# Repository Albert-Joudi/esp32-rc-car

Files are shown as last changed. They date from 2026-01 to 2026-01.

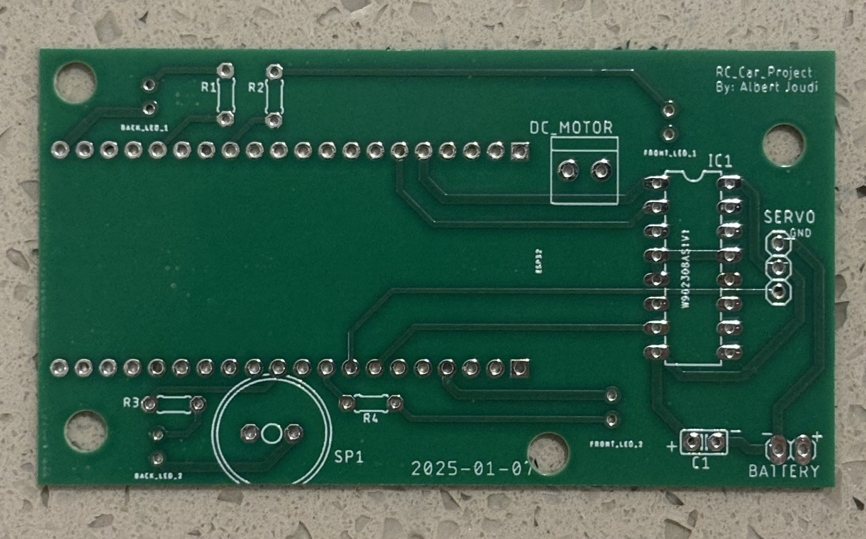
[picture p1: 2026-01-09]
media/esp32_rc_car_pcb_front_unassembled.png

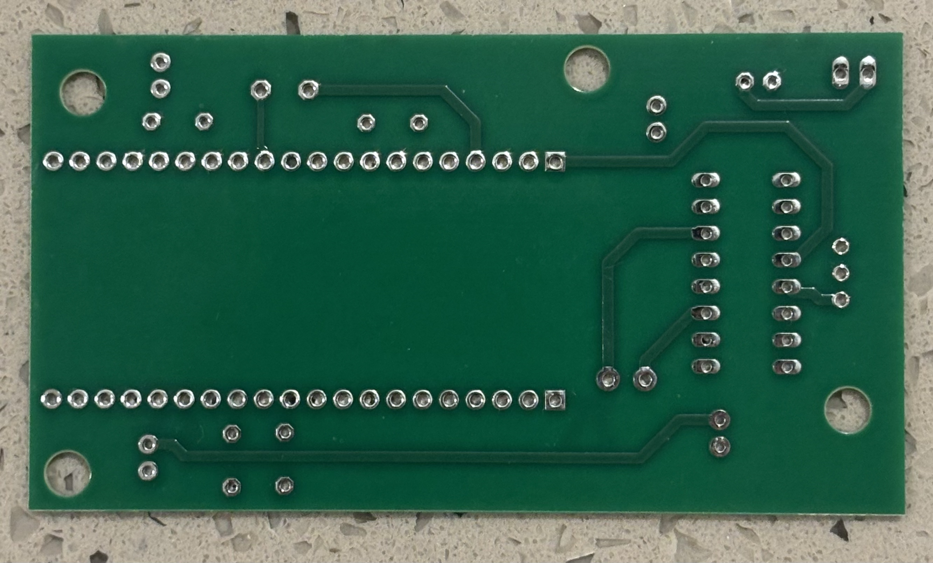
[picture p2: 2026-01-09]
media/esp32_rc_car_pcb_back_unassembled.png

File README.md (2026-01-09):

# esp32-rc-car

## Overview
The **esp32-rc-car** is a custom-built RC car controlled via Bluetooth Low Energy (BLE) using an ESP32 microcontroller. The vehicle is operated from a smartphone through the Dabble app, which provides a virtual game controller interface. The project combines embedded programming, custom PCB design, motor control, and hardware debugging.

---

## Project Media
<p align="center">
  
  
</p>
▶ Watch the ESP32 RC Car features showcase: https://youtube.com/shorts/to-kIwxq354?si=jSNwVrnpMwx3RoQd 

▶ Watch the full demo video of the ESP32 RC Car: https://youtube.com/shorts/JepBfLC0xiw?si=qRIe9IqqiM_V_Yjg

---

## Features
- BLE-based wireless control using the ESP32
- Smartphone control via the Dabble app game controller
- Start/Stop system similar to a real car ignition
- DC motor for forward and reverse motion
- Servo motor for left and right steering
- Front headlights and rear taillights
- Direction-based lighting:
  - Front LEDs activate when moving forward
  - Rear LEDs activate when reversing
- Turn signals and hazard lights with dedicated controls
- Horn functionality using a speaker
- Visual feedback (LED blinking) when starting/stopping the car

---

## Control System
- The ESP32 uses its built-in **Bluetooth Low Energy (BLE)** to communicate with a smartphone.
- The **Dabble mobile app** provides a game controller interface.
- Button presses in the app are mapped in the Arduino IDE to ESP32 GPIO pins.
- GPIO pins control:
  - DC motor
  - Servo motor
  - LEDs
  - Speaker (horn)

---

## Hardware Components
- ESP32 development board
- DC motor (rear-wheel drive)
- Servo motor (front-wheel steering)
- DRV8833 motor driver
- Speaker (horn)
- 4 LEDs:
  - 2 front headlights
  - 2 rear taillights
- Custom-designed PCB
- Power switch
- 3.7V 1100mAh Li-Po battery
- 6V 2400mAh Ni-MH battery pack

---

## Power Architecture
- **Dual power supply design**:
  - **Li-Po battery** powers the ESP32
    - Includes a physical switch to turn the system on/off
  - **Ni-MH battery pack** powers:
    - DC motor
    - Servo motor
    - LEDs
    - Speaker
- Power distribution for peripherals is handled directly on the custom PCB.

---

## PCB Design
- Custom PCB designed using **Autodesk Eagle**
- Fully **through-hole components**
- ESP32 is mounted using **headers** (not soldered directly)
- Designed for easy debugging, modification, and component replacement
- Initial motor driver (L293D) was replaced with a **DRV8833** after testing revealed insufficient motor drive strength

---

## Software & Tools
- Arduino IDE (ESP32 programming)
- Dabble mobile app (BLE controller interface)
- Autodesk Eagle (PCB design)
- Tinkercad (circuit simulation and early testing)
- Multimeter (circuit testing and debugging)

---

## Development & Debugging
- The circuit was first simulated and tested in **Tinkercad** to verify connections, motor control, and LED functionality before creating the custom PCB.  
- Multiple iterations were required to validate motor control and power delivery.  
- Problems encountered and solved:
  - Motor driver (L293D) was too weak → replaced with DRV8833
  - Front wheels initially had too much friction → wrapped tires in tape to reduce friction and allow smooth steering
  - Servo motor was not strong enough initially → adjustments made to wheel friction for smooth turning  
- Circuit simulation, real-world testing, and incremental debugging ensured reliable operation.

---

## Skills Demonstrated
- ESP32 programming and BLE integration
- Custom PCB design and layout
- Through-hole soldering and hardware assembly
- Motor driver integration and control
- Dual power supply management
- Circuit testing and debugging
- Embedded system troubleshooting
- Hardware problem solving and iterative design improvements

## Future Improvements
- Integrate motor driver directly onto PCB
- Add battery voltage monitoring
- better cable management and enclosed design

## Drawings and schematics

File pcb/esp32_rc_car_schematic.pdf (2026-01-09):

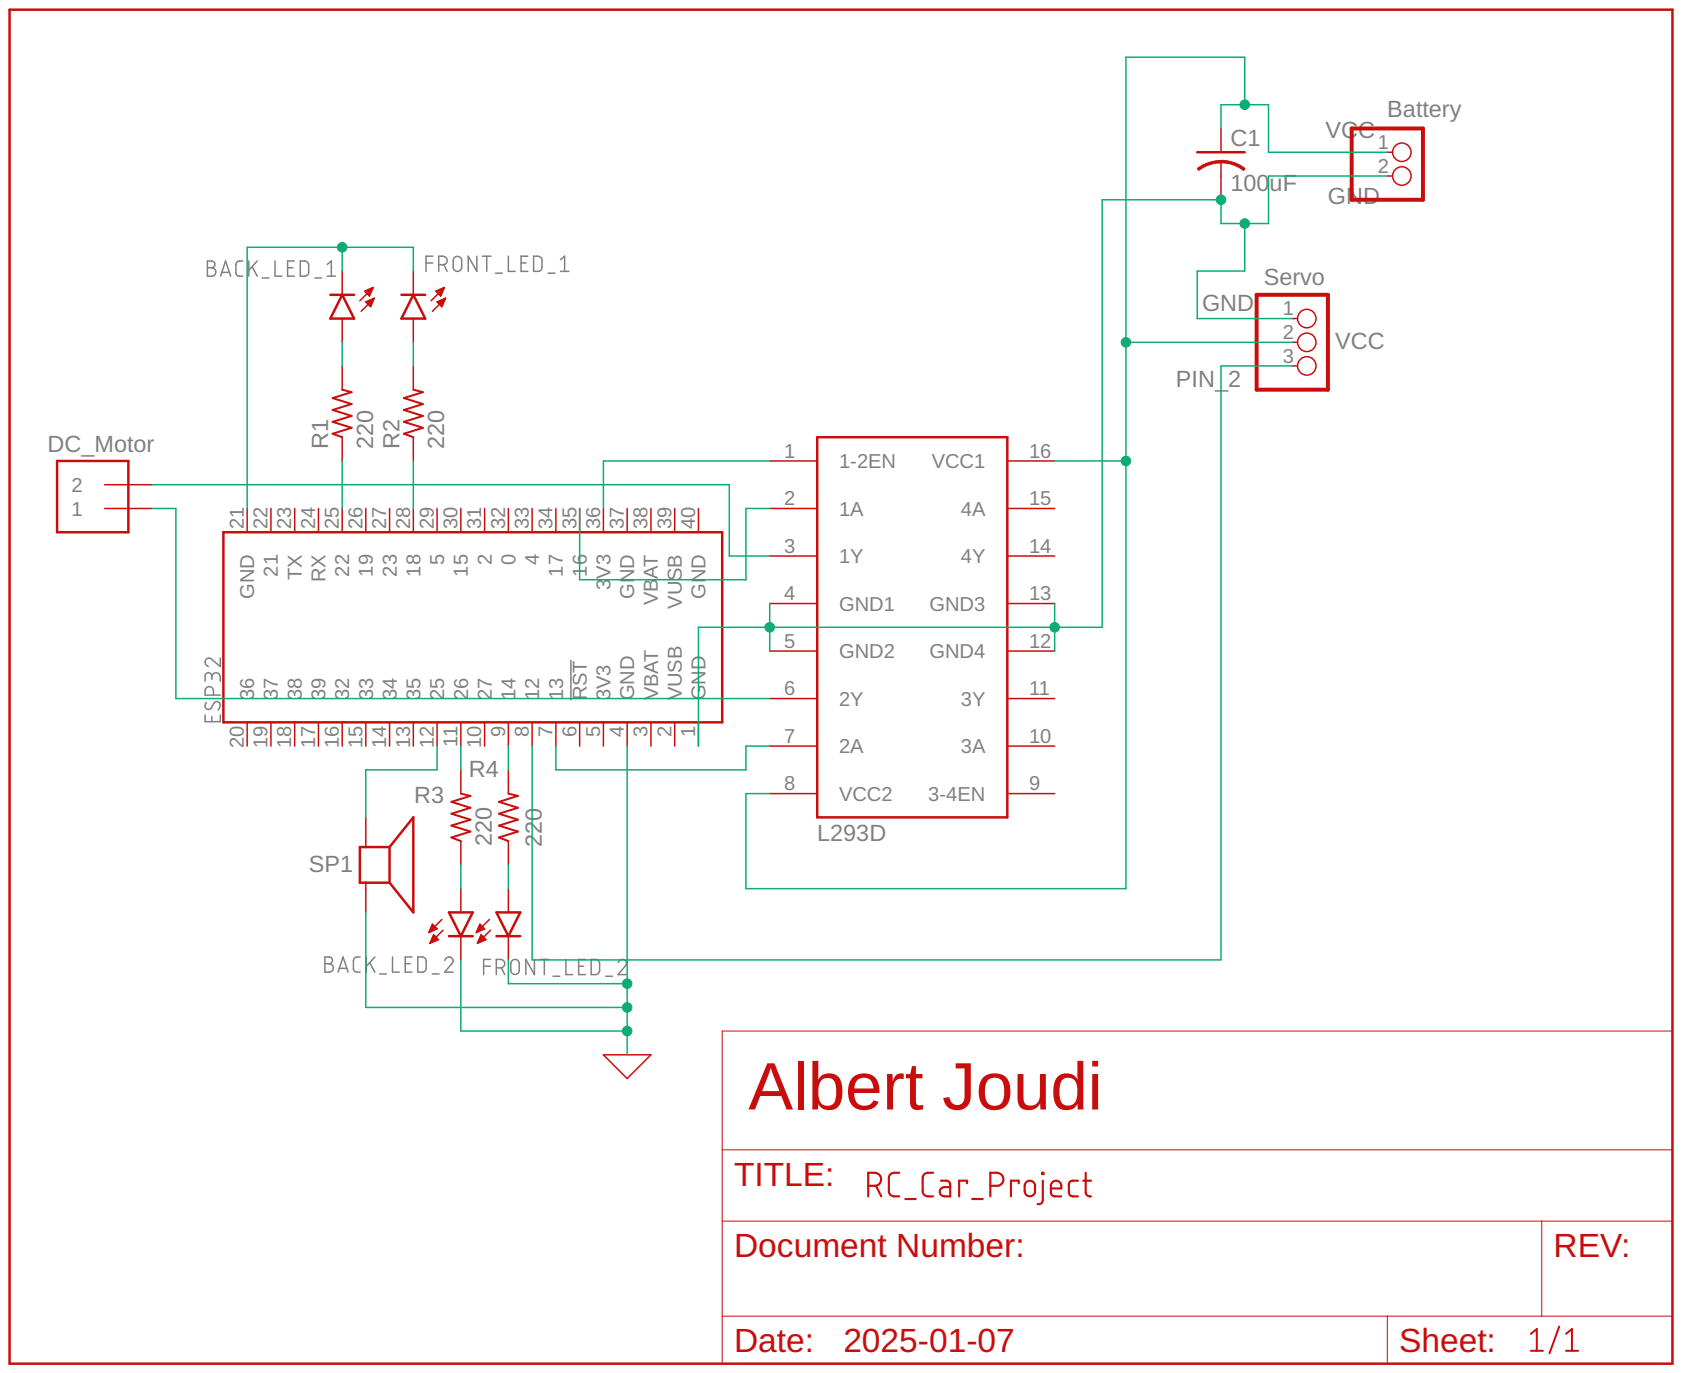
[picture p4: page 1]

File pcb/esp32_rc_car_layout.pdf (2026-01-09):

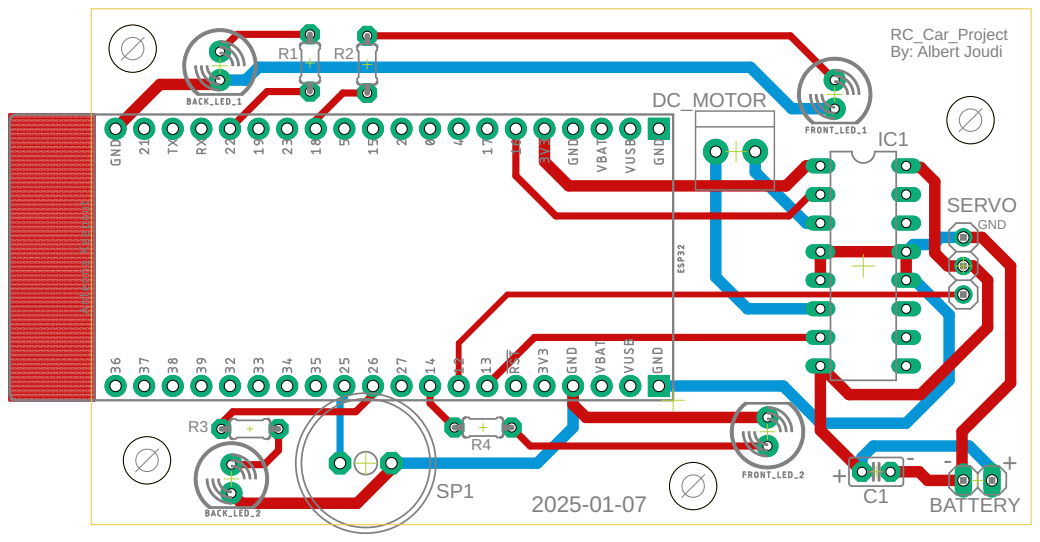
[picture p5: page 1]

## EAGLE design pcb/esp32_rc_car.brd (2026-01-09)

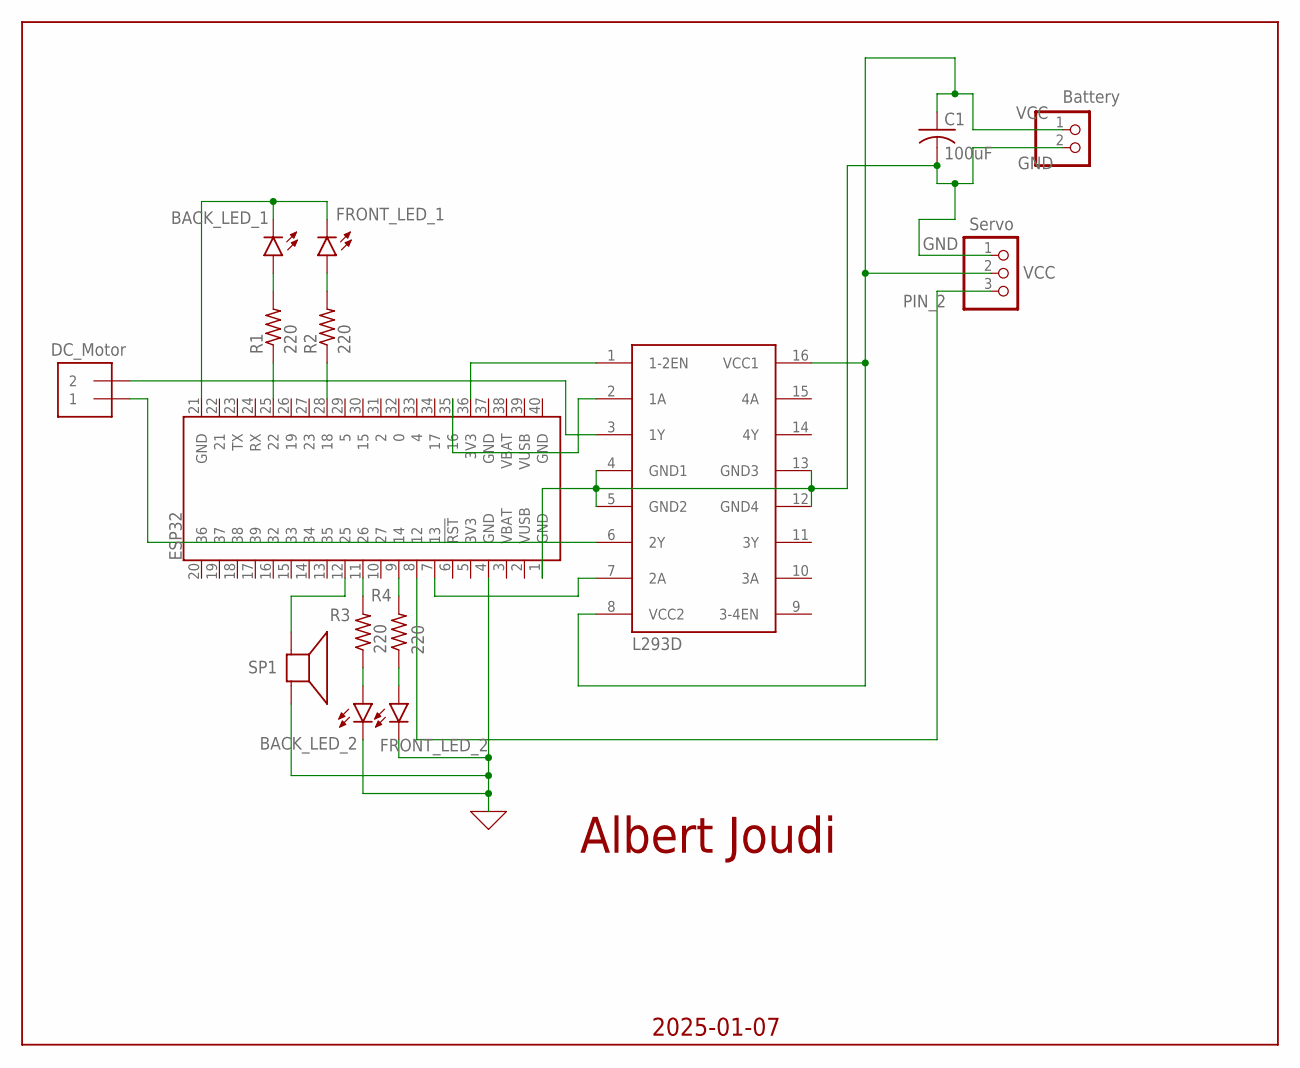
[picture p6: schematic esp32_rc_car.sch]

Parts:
BACK_LED_1, BACK_LED_2: LED-5MM-KIT-NO-SILK; LED_5MM-KIT-NO-SILK
BATTERY: PINHD-1X2; 1X02
C1: 100uF; C025-025X050
DC_MOTOR: 1X2-3.5MM
ESP32: ESP32_THING_W_ANT_KEEPOUT; ESP32_THING
FRONT_LED_1, FRONT_LED_2: LED-5MM-KIT-NO-SILK; LED_5MM-KIT-NO-SILK
IC1: L293D; DIL16
R1, R2, R3, R4: 220; 0204/5
SERVO: PINHD-1X3; 1X03
SP1: SPEAKER/AL11P; AL11P

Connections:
0: BACK_LED_2.K (C), ESP32.4 (GND), FRONT_LED_2.K (C), SP1.-
GND: BATTERY.2, C1.2, ESP32.1 (GND), IC1.4 (GND1), IC1.5 (GND2), IC1.12 (GND4), IC1.13 (GND3), SERVO.1
unnamed: ESP32.12 (25), SP1.+
unnamed: ESP32.35 (16), IC1.2 (1A)
unnamed: DC_MOTOR.2, IC1.3 (1Y)
unnamed: DC_MOTOR.1, IC1.6 (2Y)
unnamed: ESP32.7 (13), IC1.7 (2A)
unnamed: BACK_LED_2.A, R3.1
unnamed: ESP32.28 (18), R2.1
unnamed: ESP32.11 (26), R3.2
unnamed: ESP32.25 (22), R1.1
unnamed: ESP32.9 (14), R4.2
unnamed: FRONT_LED_2.A, R4.1
unnamed: ESP32.36 (3V3), IC1.1 (1-2EN)
unnamed: FRONT_LED_1.A, R2.2
unnamed: BACK_LED_1.A, R1.2
unnamed: BACK_LED_1.K (C), ESP32.21 (GND), FRONT_LED_1.K (C)
PIN_2: ESP32.8 (12), SERVO.3
VCC: BATTERY.1, C1.1, IC1.8 (VCC2), IC1.16 (VCC1), SERVO.2

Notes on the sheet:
Albert Joudi
DC_Motor
Battery
Servo
2025-01-07

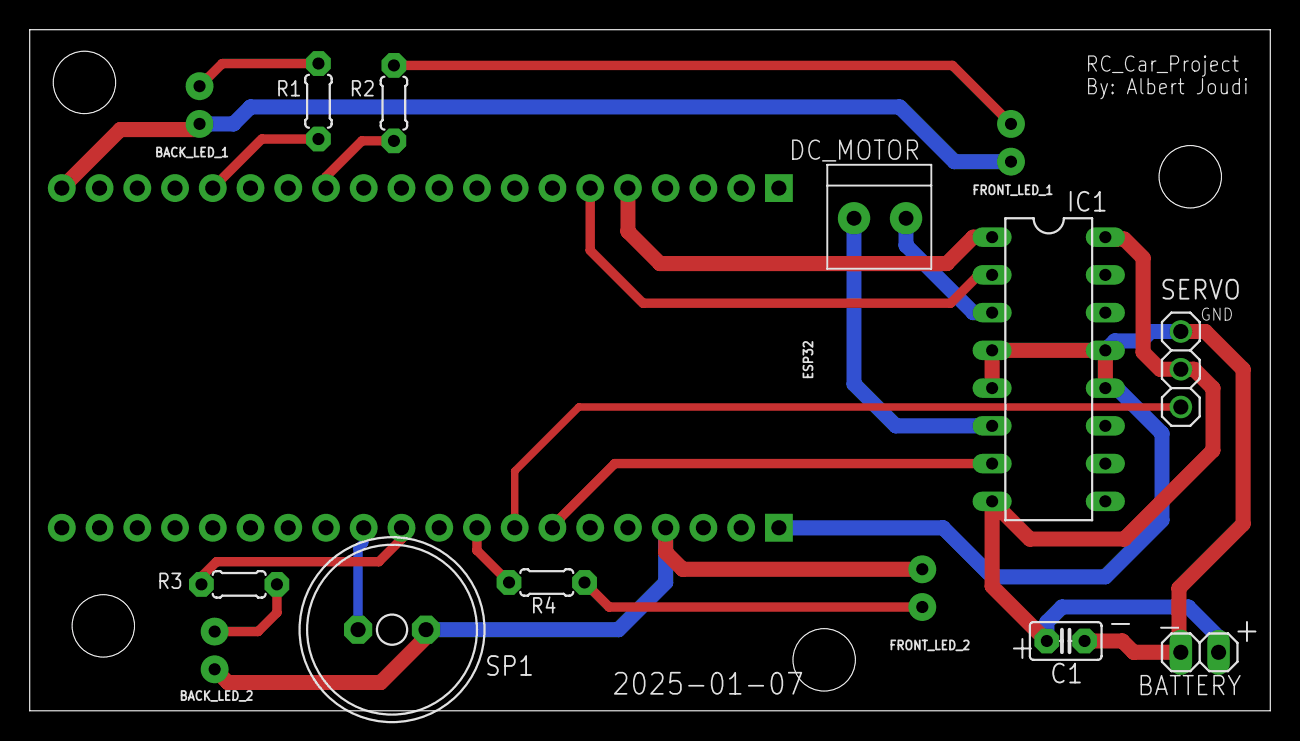
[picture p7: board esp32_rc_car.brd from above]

Board: 2 copper layers, 83.5 x 45.8 mm, 15 parts (0 on the bottom side), 19 nets.

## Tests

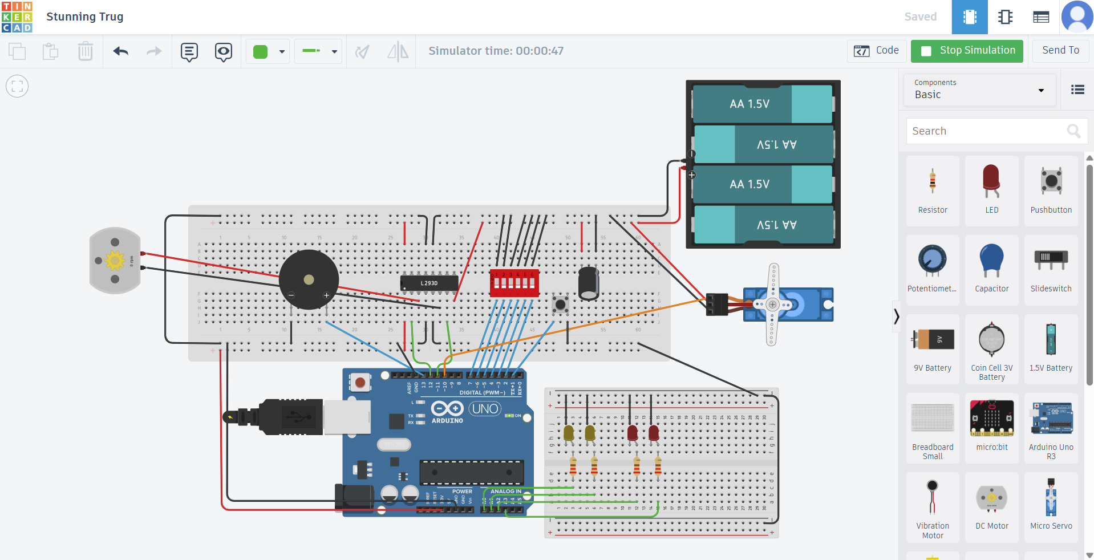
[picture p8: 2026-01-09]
media/esp32_rc_car_tinkercad_test_circuit.png

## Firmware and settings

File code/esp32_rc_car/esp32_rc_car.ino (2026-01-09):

#include <DabbleESP32.h>
#include <ESP32Servo.h> 

// Motor pins
const int motor1Pin1 = 16;
const int motor1Pin2 = 13;

// LED pins
const int leftHeadlightPin = 18;
const int rightHeadlightPin = 14;
const int leftBacklightPin = 22;
const int rightBacklightPin = 26;

// Speaker pin
const int speakerPin = 25;

// Servo pin
const int servoPin = 12;

// Servo object
Servo steeringServo; 
int servoPosition = 90;  // Default center position
bool leftPressedLast = false;
bool rightPressedLast = false;

// Turn signal logic
unsigned long previousBlinkTime = 0;
const int blinkInterval = 500; 
bool blinkState = false;

// Car state
bool carOn = false;

// Direction change timing
unsigned long lastDirectionChangeTime = 0;
const unsigned long directionChangeDelay = 50;

// Function declarations
void flashLightsAndBeep(int times, int duration);
void flashLights(int times, int duration);
void stopMotors();
void turnOffLights();

void setup() {
  pinMode(motor1Pin1, OUTPUT);
  pinMode(motor1Pin2, OUTPUT);
  pinMode(leftHeadlightPin, OUTPUT);
  pinMode(rightHeadlightPin, OUTPUT);
  pinMode(leftBacklightPin, OUTPUT);
  pinMode(rightBacklightPin, OUTPUT);
  pinMode(speakerPin, OUTPUT);

  // Attach the servo
  steeringServo.attach(servoPin, 500, 2500);
  steeringServo.write(servoPosition);

  Dabble.begin("MyCarController");
}

void loop() {
  Dabble.processInput();  // Process GamePad input

  bool upPressed = GamePad.isUpPressed();
  bool downPressed = GamePad.isDownPressed();
  bool leftPressed = GamePad.isLeftPressed();
  bool rightPressed = GamePad.isRightPressed();
  bool trianglePressed = GamePad.isTrianglePressed();
  bool squarePressed = GamePad.isSquarePressed();
  bool circlePressed = GamePad.isCirclePressed();
  bool crossPressed = GamePad.isCrossPressed();
  bool startPressed = GamePad.isStartPressed();
  bool selectPressed = GamePad.isSelectPressed();

  // Handle car start
  if (startPressed && !carOn) {
    carOn = true;
    flashLightsAndBeep(2, 200);
  }

  // Handle car stop
  if (selectPressed && carOn) {
    carOn = false;
    flashLights(2, 200);
  }

  // If the car is off, skip the rest of the logic
  if (!carOn) {
    stopMotors();
    turnOffLights();
    return;
  }

  // Handle blinking logic
  unsigned long currentTime = millis();
  if (currentTime - previousBlinkTime >= blinkInterval) {
    previousBlinkTime = currentTime;
    blinkState = !blinkState;
  }

  // Hazard lights blinking logic
  if (trianglePressed) {
    digitalWrite(leftHeadlightPin, blinkState);
    digitalWrite(rightHeadlightPin, blinkState);
    digitalWrite(leftBacklightPin, blinkState);
    digitalWrite(rightBacklightPin, blinkState);
  } else {
    digitalWrite(leftHeadlightPin, LOW);
    digitalWrite(rightHeadlightPin, LOW);
    digitalWrite(leftBacklightPin, LOW);
    digitalWrite(rightBacklightPin, LOW);
  }

  // Left turn signal logic
  if (squarePressed) {
    digitalWrite(leftHeadlightPin, blinkState);
  } else if (!trianglePressed) {
    digitalWrite(leftHeadlightPin, LOW);
  }

  // Right turn signal logic
  if (circlePressed) {
    digitalWrite(rightHeadlightPin, blinkState);
  } else if (!trianglePressed) {
    digitalWrite(rightHeadlightPin, LOW);
  }

  // Prevent forward and backward from being active at the same time
  if (upPressed && downPressed) {
    digitalWrite(motor1Pin1, LOW);
    digitalWrite(motor1Pin2, LOW);
  } else if (upPressed) {
    if (millis() - lastDirectionChangeTime >= directionChangeDelay) {
      digitalWrite(motor1Pin1, HIGH);
      digitalWrite(motor1Pin2, LOW);
      lastDirectionChangeTime = millis();
    }
    digitalWrite(leftHeadlightPin, HIGH);
    digitalWrite(rightHeadlightPin, HIGH);
    digitalWrite(leftBacklightPin, LOW);
    digitalWrite(rightBacklightPin, LOW);
  } else if (downPressed) {
    if (millis() - lastDirectionChangeTime >= directionChangeDelay) {
      digitalWrite(motor1Pin1, LOW);
      digitalWrite(motor1Pin2, HIGH);
      lastDirectionChangeTime = millis();
    }
    digitalWrite(leftHeadlightPin, LOW);
    digitalWrite(rightHeadlightPin, LOW);
    digitalWrite(leftBacklightPin, HIGH);
    digitalWrite(rightBacklightPin, HIGH);
  } else {
    digitalWrite(motor1Pin1, LOW);
    digitalWrite(motor1Pin2, LOW);
  }

  // Toggle left steering
  if (leftPressed && !leftPressedLast) {
    if (servoPosition == 60) {
      servoPosition = 96;  // Reset to center + 6° to compensate for design issue 
    } else {
      servoPosition = 60;  // Turn left
    }
    steeringServo.write(servoPosition);
  }
  leftPressedLast = leftPressed; // Update last state

  // Toggle right steering
  if (rightPressed && !rightPressedLast) {
    if (servoPosition == 120) {
      servoPosition = 90;  // Reset to center
    } else {
      servoPosition = 120;  // Turn right
    }
    steeringServo.write(servoPosition);
  }
  rightPressedLast = rightPressed; // Update last state

  // Speaker (car horn)
  if (crossPressed) {
    digitalWrite(speakerPin, HIGH); 
  } else {
    digitalWrite(speakerPin, LOW);
  }
}

// Helper function to flash all lights and beep at the same time
void flashLightsAndBeep(int times, int duration) {
  for (int i = 0; i < times; i++) {
    digitalWrite(leftHeadlightPin, HIGH);
    digitalWrite(rightHeadlightPin, HIGH);
    digitalWrite(leftBacklightPin, HIGH);
    digitalWrite(rightBacklightPin, HIGH);
    digitalWrite(speakerPin, HIGH); // Beep sound
    delay(duration);
    digitalWrite(leftHeadlightPin, LOW);
    digitalWrite(rightHeadlightPin, LOW);
    digitalWrite(leftBacklightPin, LOW);
    digitalWrite(rightBacklightPin, LOW);
    digitalWrite(speakerPin, LOW); // Stop beep
    delay(duration);
  }
}

// Helper function to flash all lights
void flashLights(int times, int duration) {
  for (int i = 0; i < times; i++) {
    digitalWrite(leftHeadlightPin, HIGH);
    digitalWrite(rightHeadlightPin, HIGH);
    digitalWrite(leftBacklightPin, HIGH);
    digitalWrite(rightBacklightPin, HIGH);
    delay(duration);
    digitalWrite(leftHeadlightPin, LOW);
    digitalWrite(rightHeadlightPin, LOW);
    digitalWrite(leftBacklightPin, LOW);
    digitalWrite(rightBacklightPin, LOW);
    delay(duration);
  }
}

// Helper function to stop motors
void stopMotors() {
  digitalWrite(motor1Pin1, LOW);
  digitalWrite(motor1Pin2, LOW);
}

// Helper function to turn off lights
void turnOffLights() {
  digitalWrite(leftHeadlightPin, LOW);
  digitalWrite(rightHeadlightPin, LOW);
  digitalWrite(leftBacklightPin, LOW);
  digitalWrite(rightBacklightPin, LOW);
}

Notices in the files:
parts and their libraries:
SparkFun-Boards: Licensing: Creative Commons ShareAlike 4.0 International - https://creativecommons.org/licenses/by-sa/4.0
